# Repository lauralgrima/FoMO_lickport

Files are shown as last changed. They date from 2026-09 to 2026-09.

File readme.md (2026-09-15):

# Modular Lick Port — Build Guide

A capacitive-sensing, solenoid-driven water lick port for pyControl mouse behaviour rigs.

**Status:** This is open but roughly documented and does not have assembly instructions. In general this is a rough, very DIY build - being shared in case it is useful inspiration for others.  For questions, please email grimal@janelia.hhmi.org. 

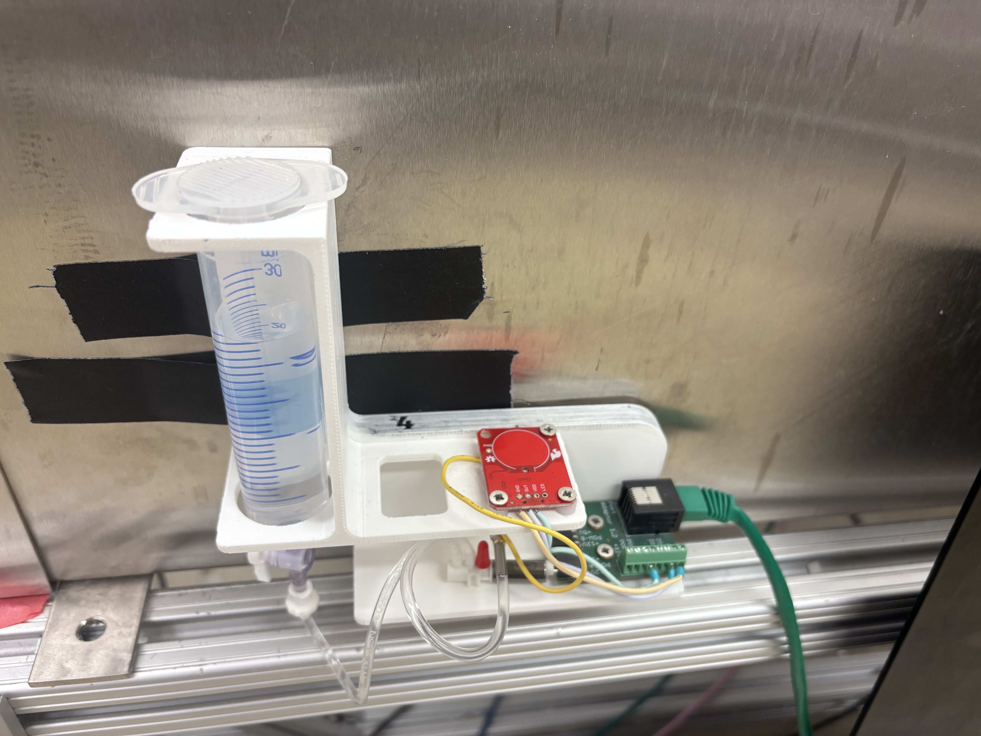
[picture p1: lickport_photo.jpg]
Lick port photo


## 1. Overview

A modular nose-poke/lick panel for head-fixed or freely-moving mouse behavior rigs, built for a pyControl system. The panel presents a metal lick tube wired as a capacitive touch sensor (so licking/tongue contact is detected without a physical microswitch), and dispenses a gravity-fed water reward through a Lee Company solenoid valve. Everything connects to the rig's pyControl Breakout Board through a Port Adapter board.

## 2. Bill of materials

| Item | Part / model | Notes |
|---|---|---|
| 3D printed panel | `modular_poke-panel_slide V2.stl` | see §3 |
| Capacitive touch sensor | SparkFun AT42QT1011 breakout (SEN-12961) | single-channel touch IC |
| Port adapter | [pyControl Port Adapter](https://github.com/pyControl/hardware/tree/master/Port_adapter) | breaks an RJ45 behaviour port out to screw terminals |
| I/O hub | [pyControl Breakout Board](https://github.com/pyControl/hardware/tree/master/Breakout_board) | 6× behaviour ports, connects to host PC |
| Solenoid valve | Lee Company **LHQA2431220H** ("silent" solenoid, 3-port, 24V nominal) | run here at +12V from the port adapter — see §4.3 |
| Reservoir | Syringe, gravity-fed (no pump) | mounted above the panel, feeds the valve's back port |
| Tubing | Rubber tubing, solenoid middle port → lick tube | |
| Cabling | Cat5/6 (RJ45) patch cable, port adapter → breakout board | |
| Lick tube | Metal tube, doubles as the touch electrode | contacted via a hollow pin threaded around the tube and soldered on — see §4.1 |

## 3. Mechanical — 3D printed part

File: `modular_poke-panel_slide V2.stl` (binary STL, ~5.7 MB, 113,730 triangles).

## 4. Electronics

Wiring & fluidics diagram

### 4.1 Capacitive touch sensor — SparkFun AT42QT1011

| Pin | Function | Wiring |
|---|---|---|
| VDD/VCC | Power, 1.8–5V | → port adapter **+5V** terminal |
| GND | Ground | → port adapter **GND** terminal |
| OUT | Digital output — **HIGH while touched, LOW otherwise** | → port adapter **DIO_A** terminal |
| PAD | Sense electrode connection (extends the touch surface to an external electrode) | → lick tube |

The PAD wire is what makes the metal tube itself the touch surface: a hollow pin is threaded around the outside of the tube and the wire is soldered to it (both conductive), effectively wrapping the tube in the sense electrode. All four connections (VDD, GND, OUT, PAD) are accounted for.

### 4.2 pyControl Port Adapter

The adapter breaks one behaviour port's RJ45 pins out to screw terminals, matching the standard pyControl behaviour-port pinout:

| RJ45 pin | Signal |
|---|---|
| 1 | DIO_A |
| 2 | GND |
| 3 | POW_A |
| 4 | DIO_B |
| 5 | special function |
| 6 | +5V |
| 7 | POW_B |
| 8 | +12V |

It also has three headers carrying the driver (POW) lines plus +5V/+12V, meant for plugging a solenoid or lamp directly in — this is what you're using for the Lee solenoid.

Suggested wiring (channel "A"):

- Cap sensor **VCC → +5V** terminal
- Cap sensor **GND → GND** terminal
- Cap sensor **OUT → DIO_A** terminal
- Solenoid **→ POW_A / +12V** header (POW lines are low-side switches: pyControl grounds the POW line when the valve should open, so the solenoid's other lead sits at +12V continuously; each POW line can sink up to 200 mA)

Note on voltage: the LHQA2431220H is nominally a 24V valve, but the port adapter's driver headers only expose +5V/+12V, so it's being run under-voltage at +12V here. Nevertheless, this works fine if the pyControl breakout board is powered by a 24V plug. (Can add a heatsink if concerned about burning the board out). 

### 4.3 Solenoid & fluidics — LHQA2431220H (3-port)

- **Front port** (nearest the electrical pins): glued shut, unused
- **Middle port**: rubber tubing → lick tube (outlet, to the mouse)
- **Back port**: fed by the gravity-fed syringe reservoir (inlet)

### 4.4 RJ45 / Breakout Board

Port adapter → Cat5/6 patch cable → any one of the 6 numbered ports on the Breakout Board → USB/serial to the host PC running the pyControl GUI. Which port number you use just needs to match what you reference in the hardware definition file below.

## 5. Firmware — pyControl

- **[`hex_port.py`](./hex_port.py)** — custom device class: a single cap-sensor + solenoid pair on one behaviour port (`DIO_A` for the touch sensor, `POW_A` for the solenoid). Note: this fixes a bug from the original version, `value()` referenced `self.input`, which was never set (the attribute is named `self.cap_sensor`) and would have raised `AttributeError` the first time it was called.
- **[`hardware_definition.py`](./hardware_definition.py)** — instantiates the board and `port1 = Hex_port(...)`, wiring `'lick1'`/`'lick_off1'` events to the touch sensor.
- **[`simple_reward_task.py`](./simple_reward_task.py)** — minimal task illustrating the core lick → reward loop (your actual production task additionally tracks per-port reward availability across a 6-port array with staggered timers, an ITI, and a session timer — this strips that away to just show the pattern: wait for a lick, open the solenoid for a fixed pulse, close it, go back to waiting).

`port1` exposes `port1.SOL` (a `Digital_output` on POW_A, switched with `.on()`/`.off()`) and `port1.value()` to poll current touch state.

## 6. Testing & troubleshooting checklist

- [ ] Touch tube with sensor powered → `port1.value()` / OUT should read HIGH; release → LOW
- [ ] Trigger `port1.SOL.on()` briefly from the pyControl GUI and confirm water reaches the tube with no leaks
- [ ] Calibrate reward pulse duration against actual dispensed volume (weigh output over ~20 pulses)

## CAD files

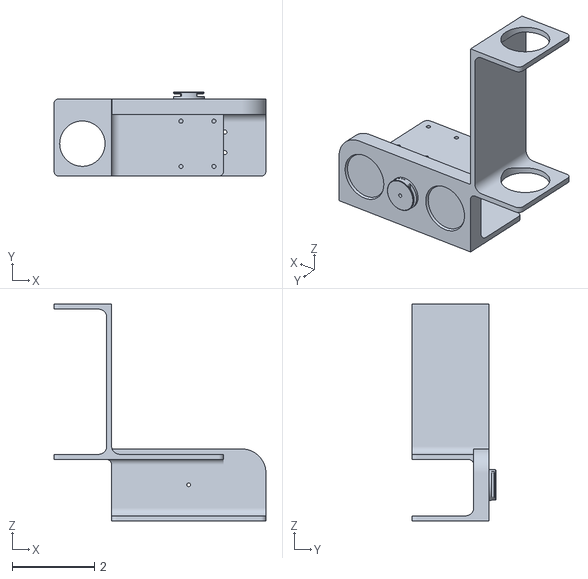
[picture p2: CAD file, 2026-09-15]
modular_poke-panel_slide V2.stl
5.15 x 2.04 x 5.27

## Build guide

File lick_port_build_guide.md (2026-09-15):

# Modular Lick Port — Build Guide

A capacitive-sensing, solenoid-driven water lick port for pyControl mouse behaviour rigs.

**Status:** internal lab reference, not for external distribution.

## 1. Overview

A modular nose-poke/lick panel for head-fixed or freely-moving mouse behavior rigs, built for a pyControl system. The panel presents a metal lick tube wired as a capacitive touch sensor (so licking/tongue contact is detected without a physical microswitch), and dispenses a gravity-fed water reward through a Lee Company solenoid valve. Everything connects to the rig's pyControl Breakout Board through a Port Adapter board.

## 2. Bill of materials

| Item | Part / model | Notes |
|---|---|---|
| 3D printed panel | `modular_poke-panel_slide V2.stl` | see §3 |
| Capacitive touch sensor | SparkFun AT42QT1011 breakout (SEN-12961) | single-channel touch IC |
| Port adapter | [pyControl Port Adapter](https://github.com/pyControl/hardware/tree/master/Port_adapter) | breaks an RJ45 behaviour port out to screw terminals |
| I/O hub | [pyControl Breakout Board](https://github.com/pyControl/hardware/tree/master/Breakout_board) | 6× behaviour ports, connects to host PC |
| Solenoid valve | Lee Company **LHQA2431220H** ("silent" solenoid, 3-port, 24V nominal) | run here at +12V from the port adapter — see §4.3 |
| Reservoir | Syringe, gravity-fed (no pump) | mounted above the panel, feeds the valve's back port |
| Tubing | Rubber tubing, solenoid middle port → lick tube | |
| Cabling | Cat5/6 (RJ45) patch cable, port adapter → breakout board | |
| Lick tube | Metal tube, doubles as the touch electrode | contacted via a hollow pin threaded around the tube and soldered on — see §4.1 |

## 3. Mechanical — 3D printed part

File: `modular_poke-panel_slide V2.stl` (binary STL, ~5.7 MB, 113,730 triangles).

## 4. Electronics

Wiring & fluidics diagram

*(diagram file: `wiring_diagram.svg`, alongside this guide — keep it in the same folder for the image link above to resolve)*

### 4.1 Capacitive touch sensor — SparkFun AT42QT1011

| Pin | Function | Wiring |
|---|---|---|
| VDD/VCC | Power, 1.8–5V | → port adapter **+5V** terminal |
| GND | Ground | → port adapter **GND** terminal |
| OUT | Digital output — **HIGH while touched, LOW otherwise** | → port adapter **DIO_A** terminal |
| PAD | Sense electrode connection (extends the touch surface to an external electrode) | → lick tube |

The PAD wire is what makes the metal tube itself the touch surface: a hollow pin is threaded around the outside of the tube and the wire is soldered to it (both conductive), effectively wrapping the tube in the sense electrode. All four connections (VDD, GND, OUT, PAD) are accounted for.

### 4.2 pyControl Port Adapter

The adapter breaks one behaviour port's RJ45 pins out to screw terminals, matching the standard pyControl behaviour-port pinout:

| RJ45 pin | Signal |
|---|---|
| 1 | DIO_A |
| 2 | GND |
| 3 | POW_A |
| 4 | DIO_B |
| 5 | special function |
| 6 | +5V |
| 7 | POW_B |
| 8 | +12V |

It also has three headers carrying the driver (POW) lines plus +5V/+12V, meant for plugging a solenoid or lamp directly in — this is what you're using for the Lee solenoid.

Suggested wiring (channel "A"):

- Cap sensor **VCC → +5V** terminal
- Cap sensor **GND → GND** terminal
- Cap sensor **OUT → DIO_A** terminal
- Solenoid **→ POW_A / +12V** header (POW lines are low-side switches: pyControl grounds the POW line when the valve should open, so the solenoid's other lead sits at +12V continuously; each POW line can sink up to 200 mA)

Note on voltage: the LHQA2431220H is nominally a 24V valve, but the port adapter's driver headers only expose +5V/+12V, so it's being run under-voltage at +12V here. "Silent" Lee valves are commonly run this way (slower/quieter actuation, less force than at rated voltage) — you've confirmed this works fine in practice for this setup, just flagging it here so it's documented rather than assumed.

### 4.3 Solenoid & fluidics — LHQA2431220H (3-port)

- **Front port** (nearest the electrical pins): glued shut, unused
- **Middle port**: rubber tubing → lick tube (outlet, to the mouse)
- **Back port**: fed by the gravity-fed syringe reservoir (inlet)

### 4.4 RJ45 / Breakout Board

Port adapter → Cat5/6 patch cable → any one of the 6 numbered ports on the Breakout Board → USB/serial to the host PC running the pyControl GUI. Which port number you use just needs to match what you reference in the hardware definition file below.

## 5. Firmware — pyControl

Three pyControl code files live alongside this guide in the repo (kept as separate files rather than duplicated here, so there's one source of truth):

- **[`hex_port.py`](./hex_port.py)** — custom device class: a single cap-sensor + solenoid pair on one behaviour port (`DIO_A` for the touch sensor, `POW_A` for the solenoid). Note: this fixes a bug from the original version, `value()` referenced `self.input`, which was never set (the attribute is named `self.cap_sensor`) and would have raised `AttributeError` the first time it was called.
- **[`hardware_definition.py`](./hardware_definition.py)** — instantiates the board and `port1 = Hex_port(...)`, wiring `'lick1'`/`'lick_off1'` events to the touch sensor.
- **[`simple_reward_task.py`](./simple_reward_task.py)** — minimal task illustrating the core lick → reward loop (your actual production task additionally tracks per-port reward availability across a 6-port array with staggered timers, an ITI, and a session timer — this strips that away to just show the pattern: wait for a lick, open the solenoid for a fixed pulse, close it, go back to waiting).

`port1` exposes `port1.SOL` (a `Digital_output` on POW_A, switched with `.on()`/`.off()`) and `port1.value()` to poll current touch state.

## 6. Testing & troubleshooting checklist

- [ ] Touch tube with sensor powered → `port1.value()` / OUT should read HIGH; release → LOW
- [ ] Trigger `port1.SOL.on()` briefly from the pyControl GUI and confirm water reaches the tube with no leaks
- [ ] Calibrate reward pulse duration against actual dispensed volume (weigh output over ~20 pulses)

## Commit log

2026-09-15 Photo + wiring diagram
2026-09-15 Create modular_poke-panel_slide V2.stl
    [modular_poke-panel_slide V2.stl]
